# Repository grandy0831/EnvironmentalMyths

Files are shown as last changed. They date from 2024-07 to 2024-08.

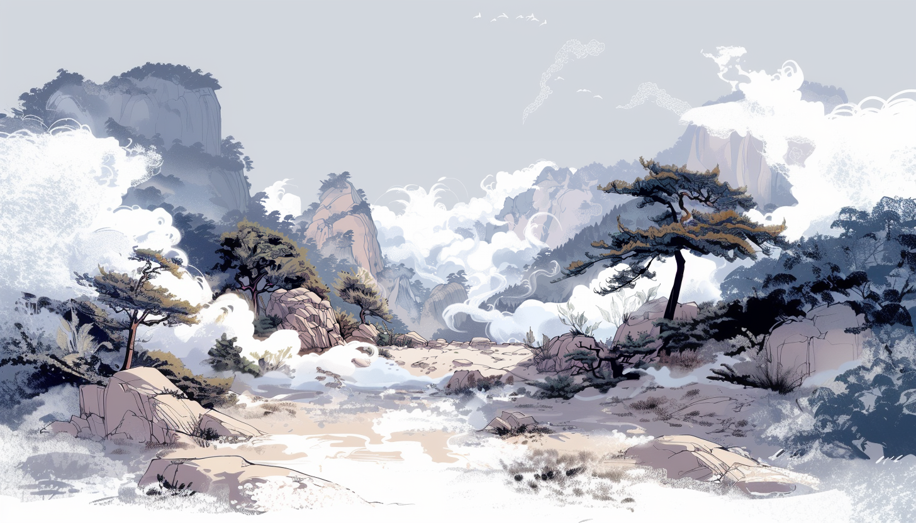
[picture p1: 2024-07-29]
Mythology Pictures/Wind-S2/W2-Background-generated by AI/W2-2.png

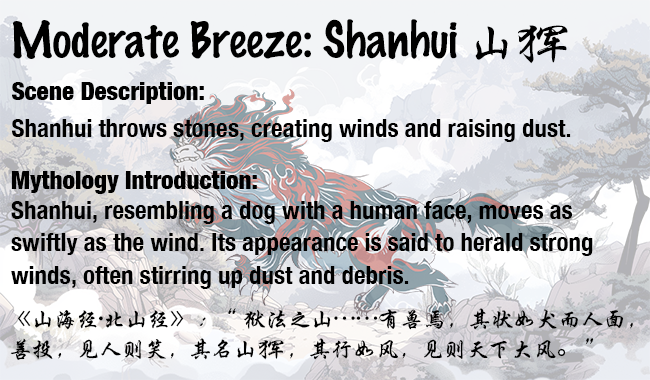
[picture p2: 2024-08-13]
Code/Final/Myths/With screen/png/Shanhui.png

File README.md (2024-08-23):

# Environmental Myths: The Fusion of Ancient Mythology and Modern Technology



## Project Overview
The Environmental Myths project brings together ancient Chinese myths and modern technology to demonstrate how ancient people interpreted natural phenomena. Utilising sensors to monitor temperature, humidity, and wind, it transforms this environmental data into dynamic displays through artistic installations featuring mechanical structures. This innovative approach not only educates the public about traditional culture and environmental changes but also revitalises ancient stories, fostering an appreciation for cultural heritage and environmental science.

## Research Questions
**Main Question:**
- How can traditional Chinese myths be integrated with modern environmental sensor technology to visualise changes in the environment?

**Sub-Questions:**
- How can a reliable outdoor environmental monitoring device be designed and constructed for long-term operation?
- How can artistic installations be designed to display environmental data captured by sensors?

## Technical Details

### Personal Weather Station Design
- **Sensor Selection**
  - DHT22 for humidity and temperature measurement.
  - Pulse Output Wind Speed Sensor for wind speed detection.
  
- **Hardware Assembly**
  - Powered by a 3.7V 1000mAh rechargeable lithium polymer battery.
  - Supported by a 1W 80*100 solar panel.
  - Managed by the DFRobot Solar Power Manager 5V.
  - Controlled by Arduino NANO ESP32 Nano for efficient data processing.

- **Enclosure**
  - Stevenson screen model 3D-printed in PETG material, which is noted for its high strength and impact resistance, ensuring durability in outdoor environments.

- **Code Implementation**
  - Incorporates Wi-Fi connectivity and an MQTT client for seamless data transmission.
  - Utilises ESP32 deep sleep mode to significantly reduce power consumption during idle times, ensuring long-term deployment without frequent maintenance.

### Artistic Installation Device Design

- **Hardware Assembly**
  - **Controller**: Utilises Arduino GIGA R1 WI-FI for robust control, featuring an extensive number of GPIOs and dedicated connectors.
  - **Servo Motors**: Three continuous rotation servos to control the movements of characters on the stage. One 25kg torque servo for angular control, tasked with switching between different scenes.
  - **Display**: Integrates a GIGA Display Shield to introduce and explain each scene.
  - **Presence Detection**: Employs a PIR sensor to detect the presence of viewers, activating the scene's movements when someone is nearby.

- **Code Implementation**
  - **Graphics and Video**: Uses ArduinoGraphics and Arduino_H7_Video.h libraries to display images.
  - **Connectivity**: Connects to a MQTT server via WI-FI to receive data from the weather station.
  - **Actuation**: Controls the servos based on received environmental data to switch scenes dynamically as environmental conditions change.

- **Enclosure Design**
  - **Stage Design**: Entirely original design created in FUSION360 for a rotatable stage that transitions between three scenes.
  - **Manufacturing**: Constructed using 3D printing, assembling the multi-scene stage prototype for interactive display.

## Installation Guide

### Hardware Installation Steps

#### Environmental Monitoring Station Setup:
- **Hardware Connection Diagram**:

PWS

- **Code Repository**: [Access the code here](https://github.com/grandy0831/EnvironmentalMyths/tree/main/Code/Final/PWS)
- **Enclosure Printing Model**: [Download the 3D model here](https://www.thingiverse.com/thing:3615016#google_vignette)
- **Internal Setup Images**:

5101723710179_ pic

#### Artistic Installation Setup:
- **Hardware Connection Diagram**:

stage_bb

- **Layer Model Functionality**:
  - **Top Layer (L0)**: Combines three devices.
  - **Scene Display (L1-1)**: Details the exhibition of scenes.
  - **Continuous Rotation Servo Space (L1-2)**: Houses the internal mechanics.
  
  5331723711250_ pic

  - **Rotation Platform (L2-1)**: Supports scene rotation, allowing space for wiring.
    
  5321723711248_ pic
  
  - **Central Servo Fixation (L2-1.5)**: Holds the central servo controlling stage rotation.
    
  5341723711592_ pic
  
  - **Display and Controls (L2-2-1, L2-2-2, L2-2-3)**: Accommodates the display, PIR sensor, switches, power sockets, and space for physical components and wiring.
  
  5311723711247_ pic

- **Model Links**: [Access models here](https://github.com/grandy0831/EnvironmentalMyths/tree/main/Model/STAGE)
- **Assembly Images by Layers**:
  
5281723711241_ pic
5291723711243_ pic

- **Final Device Scenes Presentation**:










## Deployment and Exhibition

### Weather Station Deployment
- **Deployment Photos**:
  
5231723710192_ pic
5241723710193_ pic
5261723710196_ pic

- **Operational Showcase**:
  
5031723217820_ pic

### Art Installation Setup
- **Scene Stage Deployment**: Photographs of the scene stage setup at the exhibition site.
  
c6b02fe9f156e05483c8268d89080cd7

- **Artistic Device Introduction**: [Learn more about the artistic installation](https://environmentalmyths.com/myths)

## Conclusion
This project has successfully integrated physical devices with artistic displays, creating an innovative installation that can monitor environmental data in real-time while dynamically presenting mythological stories.

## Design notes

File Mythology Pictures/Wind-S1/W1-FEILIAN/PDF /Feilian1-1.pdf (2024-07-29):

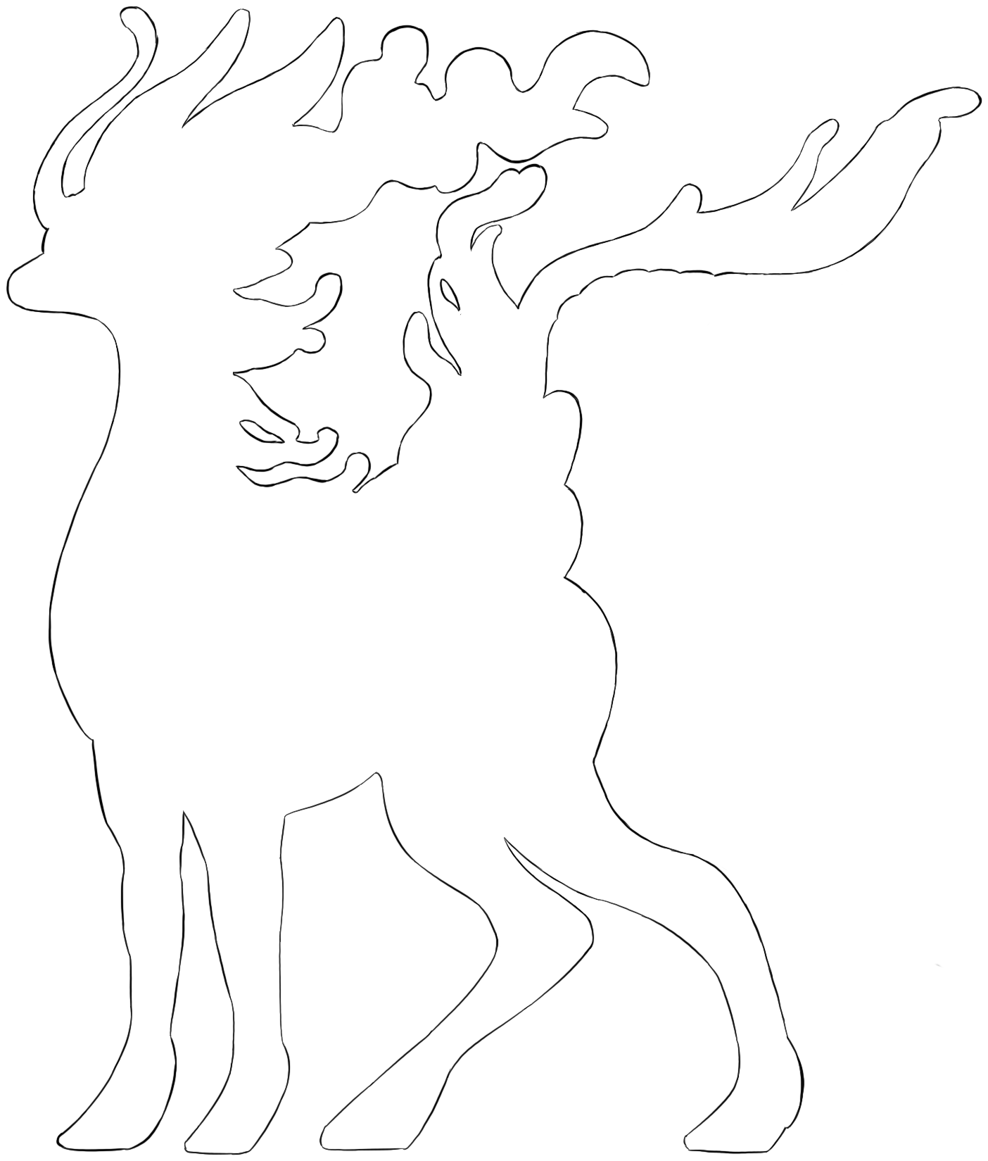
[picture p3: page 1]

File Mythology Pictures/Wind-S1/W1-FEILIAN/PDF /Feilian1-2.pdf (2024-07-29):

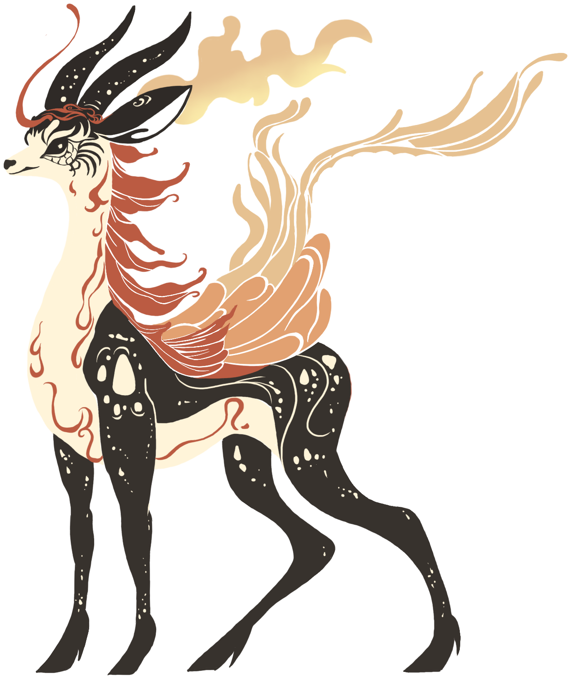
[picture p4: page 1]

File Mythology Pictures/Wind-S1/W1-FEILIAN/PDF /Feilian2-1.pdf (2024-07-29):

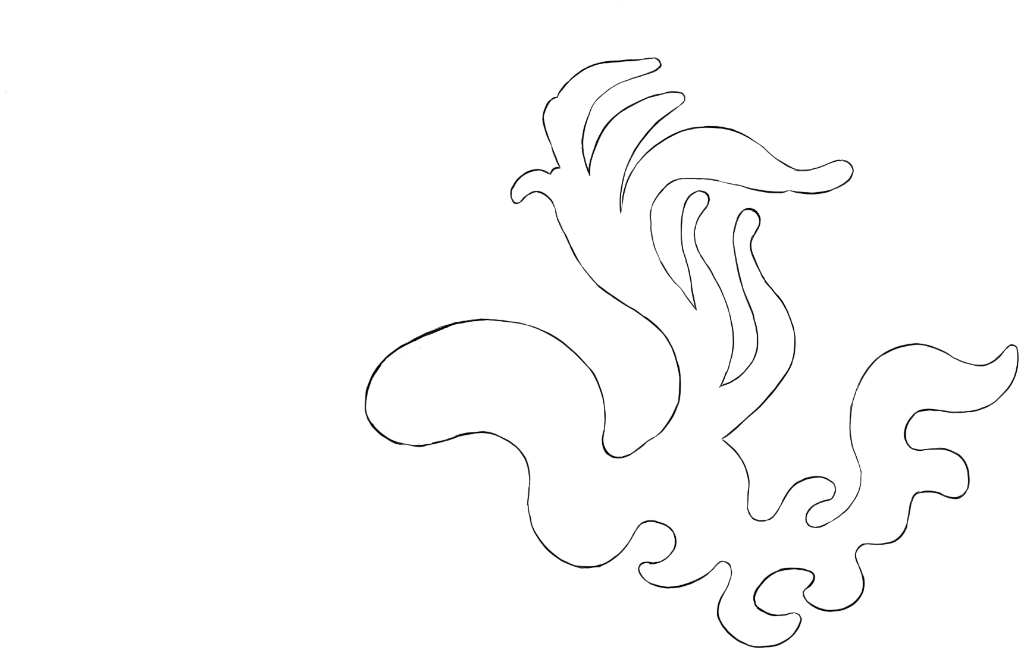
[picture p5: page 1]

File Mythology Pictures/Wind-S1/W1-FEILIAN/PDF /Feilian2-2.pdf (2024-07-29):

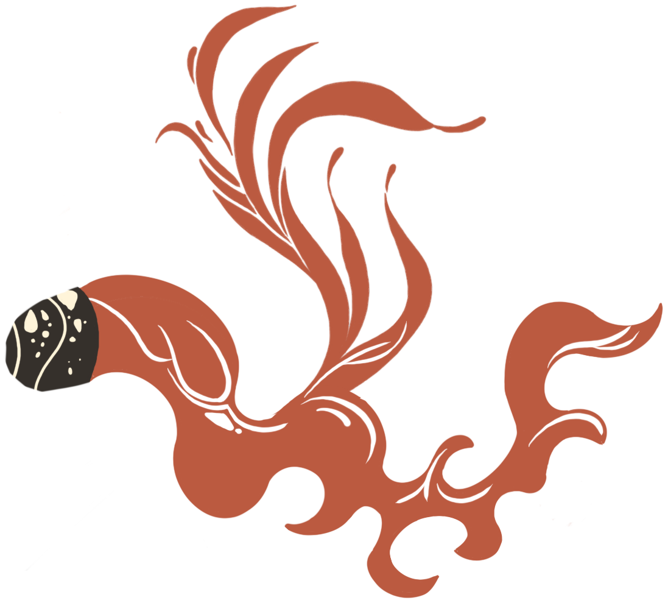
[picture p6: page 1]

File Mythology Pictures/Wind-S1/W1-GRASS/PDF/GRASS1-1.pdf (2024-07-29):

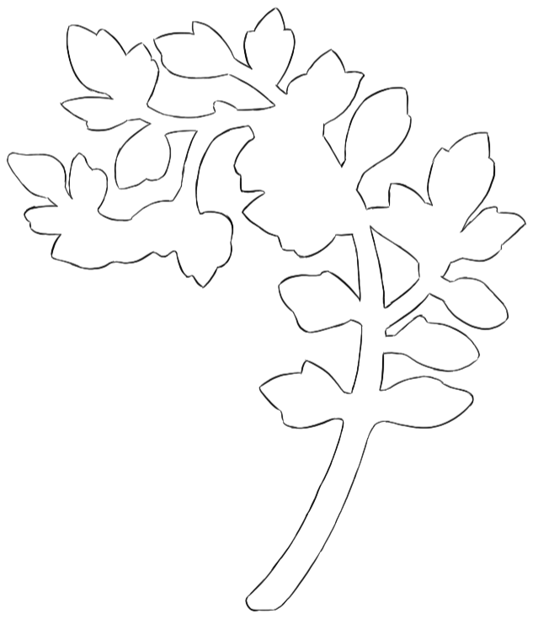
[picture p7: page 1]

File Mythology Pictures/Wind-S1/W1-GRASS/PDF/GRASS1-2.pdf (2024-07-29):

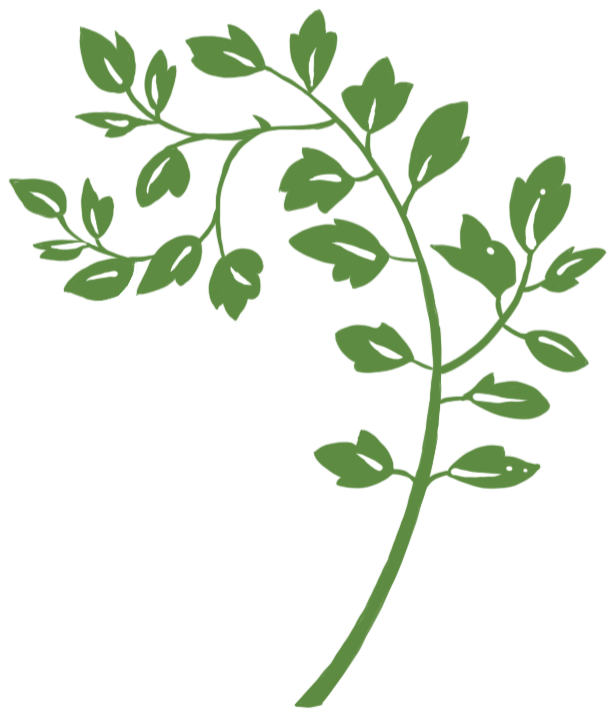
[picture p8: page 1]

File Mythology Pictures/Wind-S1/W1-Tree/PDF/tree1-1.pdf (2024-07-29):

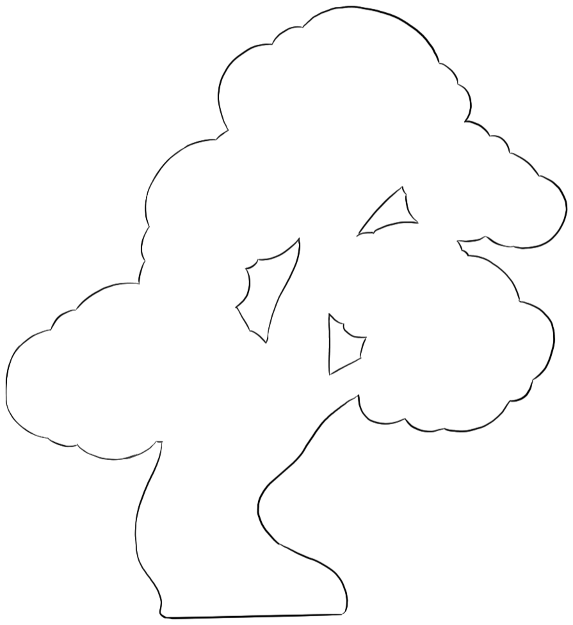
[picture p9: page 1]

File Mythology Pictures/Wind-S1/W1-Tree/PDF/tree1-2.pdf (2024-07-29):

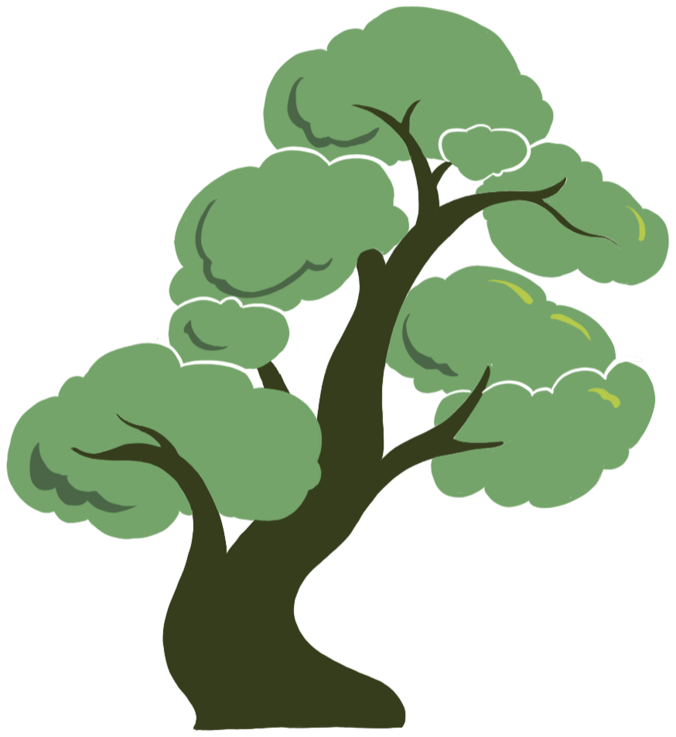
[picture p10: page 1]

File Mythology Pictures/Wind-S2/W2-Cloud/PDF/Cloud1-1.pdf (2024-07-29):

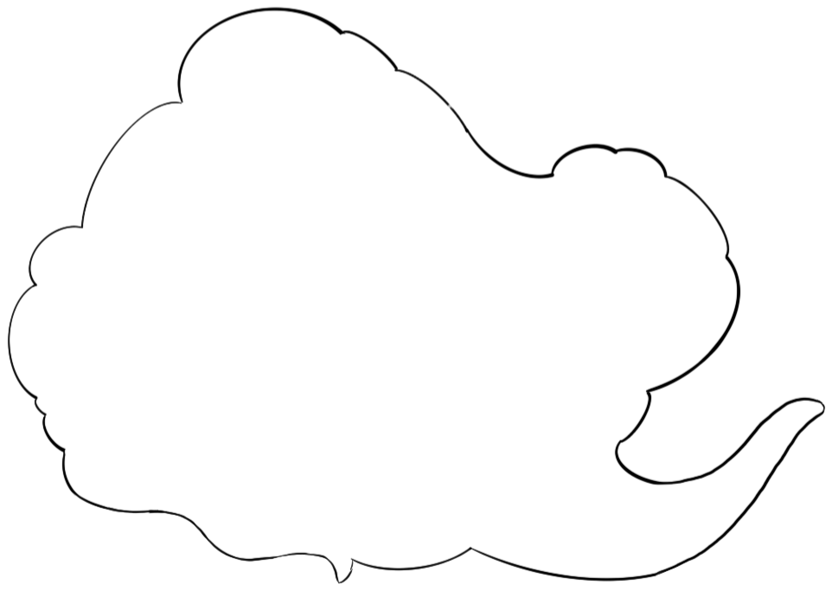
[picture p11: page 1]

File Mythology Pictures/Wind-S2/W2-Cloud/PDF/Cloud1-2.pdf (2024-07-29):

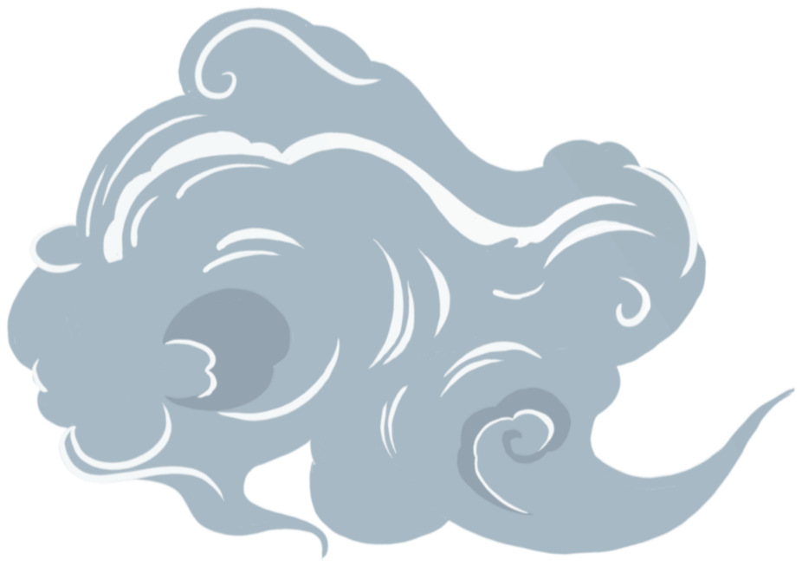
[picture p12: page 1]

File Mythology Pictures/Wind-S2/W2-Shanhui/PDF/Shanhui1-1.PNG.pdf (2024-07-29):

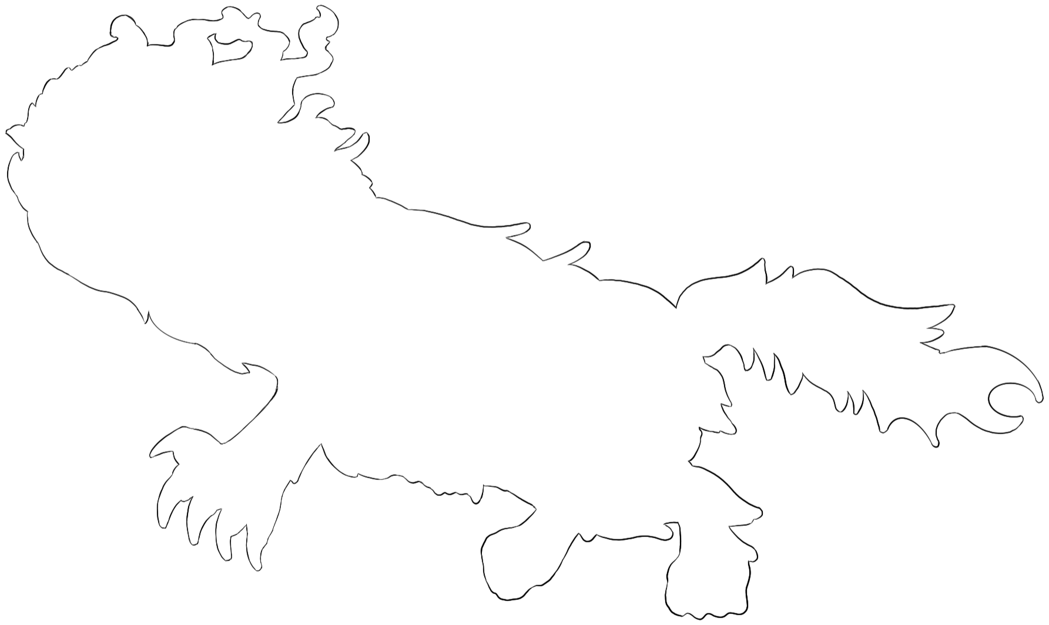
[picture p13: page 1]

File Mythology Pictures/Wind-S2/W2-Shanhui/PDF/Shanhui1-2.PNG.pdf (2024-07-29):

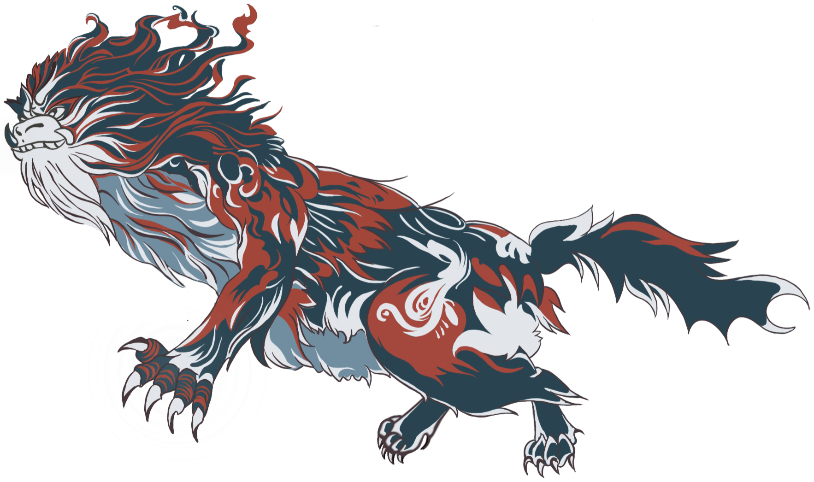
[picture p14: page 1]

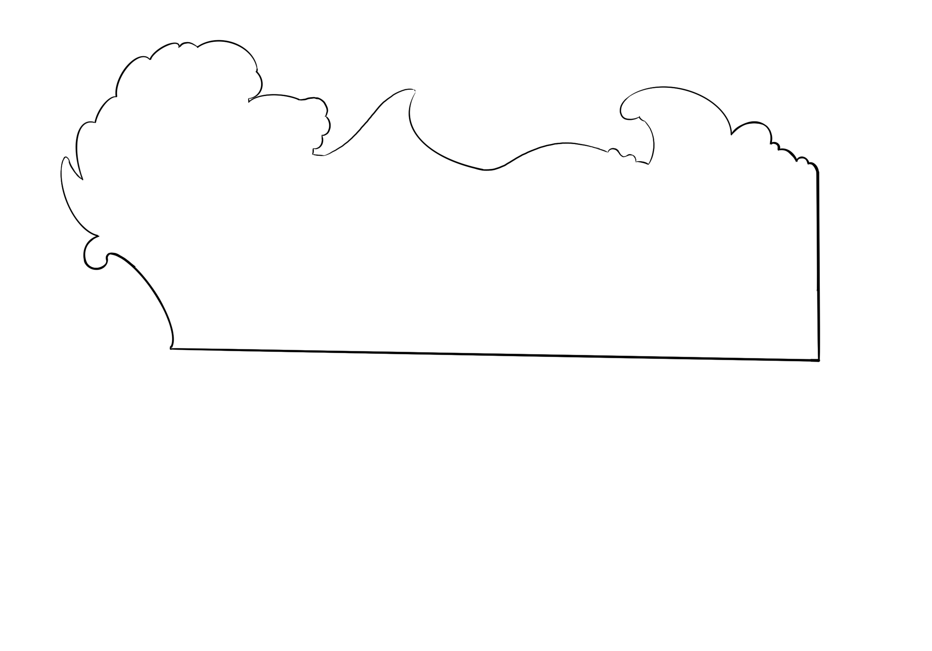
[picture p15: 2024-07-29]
Mythology Pictures/Wind-S3/W3-Wave/PNG/wave1-1.PNG

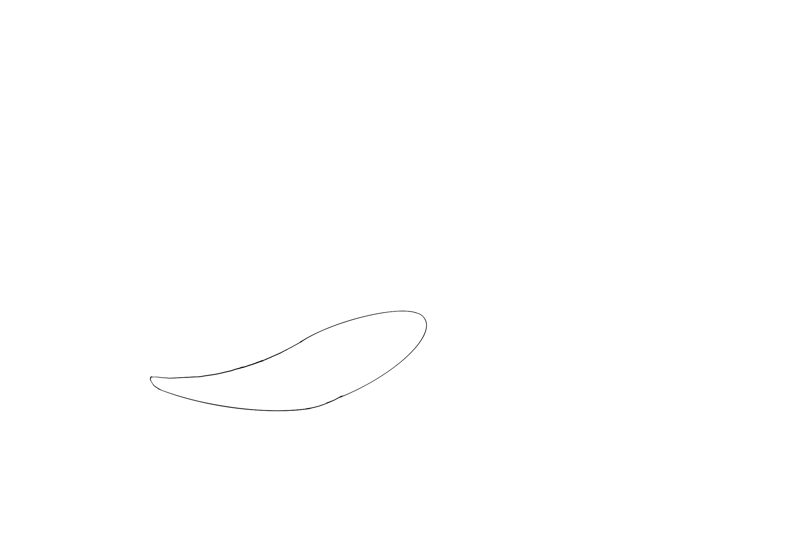
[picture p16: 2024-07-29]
Mythology Pictures/Wind-S3/W3-Kunpeng/PNG/Kunpeng1-1.PNG

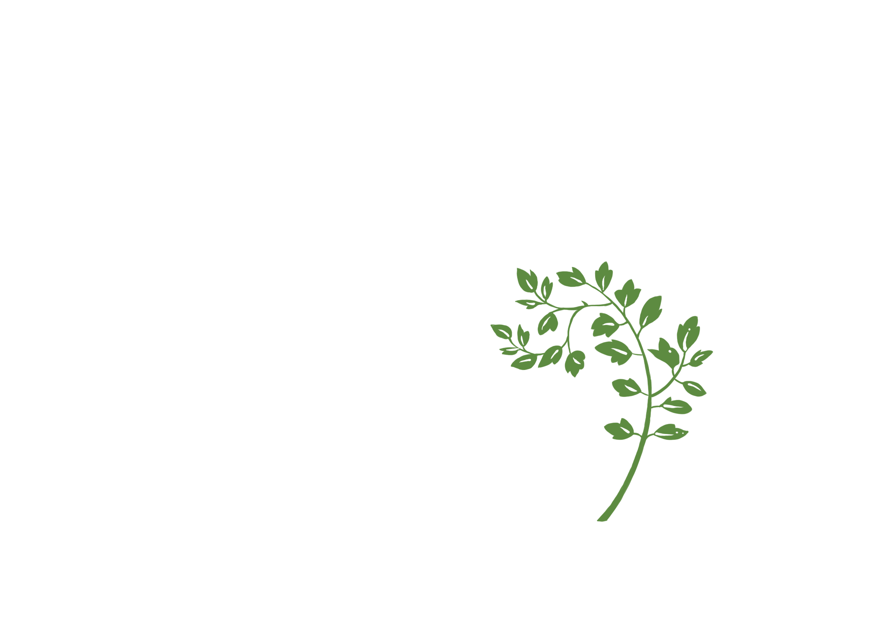
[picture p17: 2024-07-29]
Mythology Pictures/Wind-S1/W1-GRASS/PNG/GRASS1-2.PNG

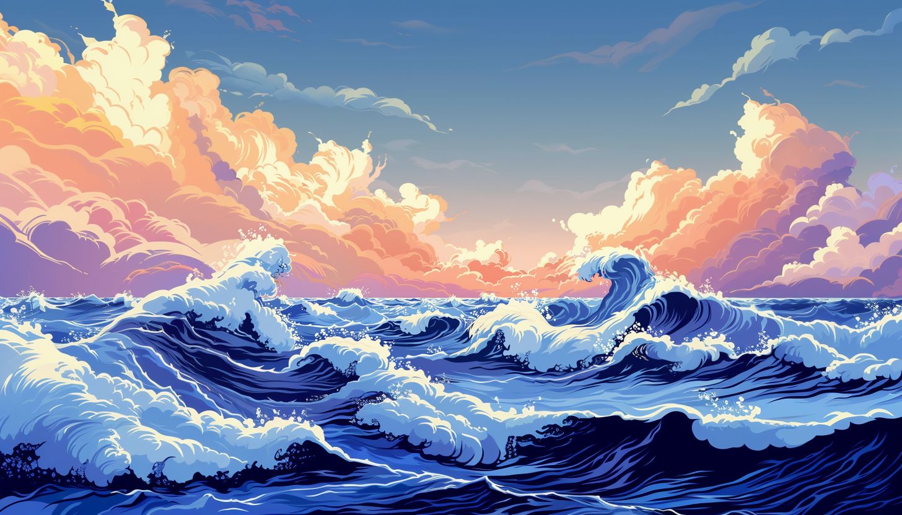
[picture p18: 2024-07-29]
Mythology Pictures/Wind-S3/W3-Background-generated by AI/W3-2.png

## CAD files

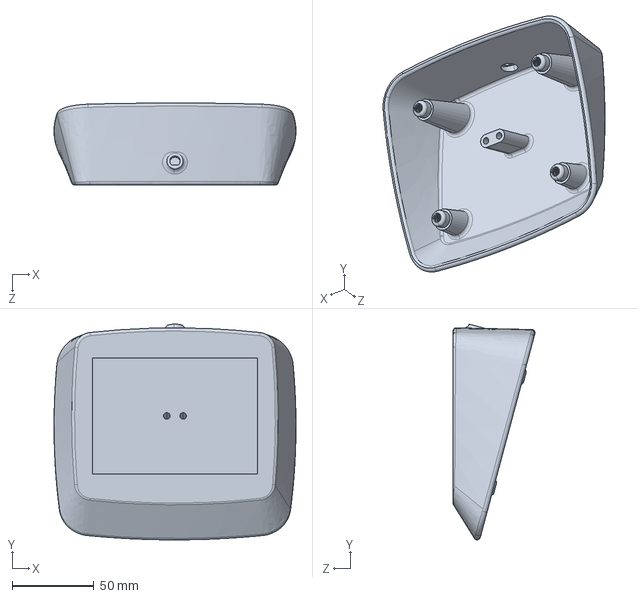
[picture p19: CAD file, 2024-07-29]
Model/PWS/Stevenson Screen for Solar Weather Station V2/Screen_Top_Cover.STEP
147.8 x 131.8 x 50.1 mm

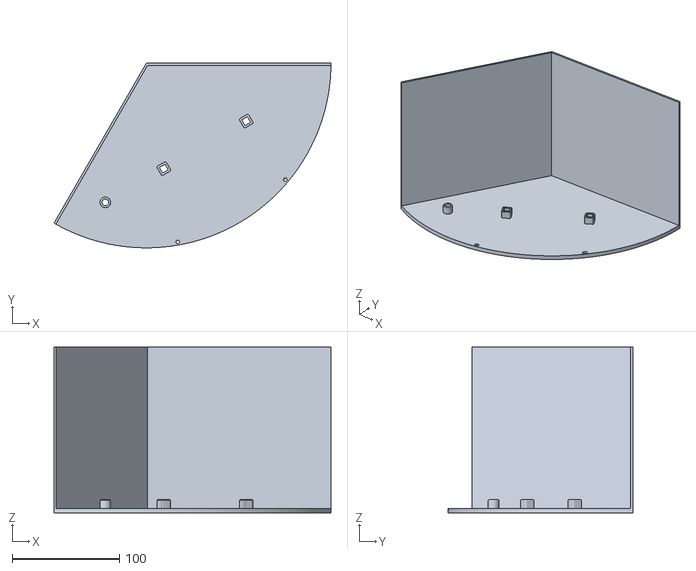
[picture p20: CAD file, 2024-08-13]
Model/STAGE/L1-1-HUM/L1-H3 .stl
257.7 x 171.8 x 154.4

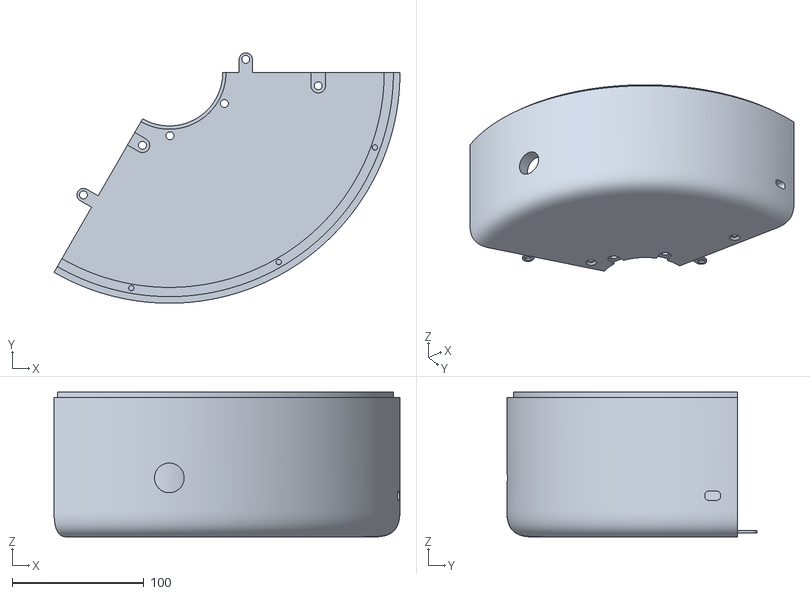
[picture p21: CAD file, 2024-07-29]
Model/STAGE/L2-2-3.stl
262.5 x 190.0 x 110.0

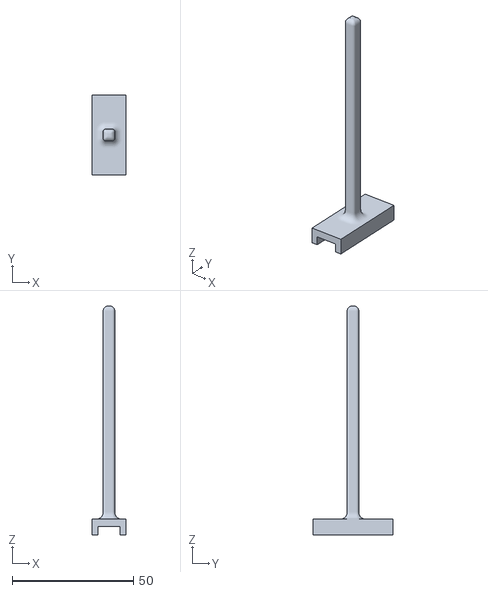
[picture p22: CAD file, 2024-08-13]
Model/STAGE/Other/G2.stl
14.0 x 33.0 x 94.5

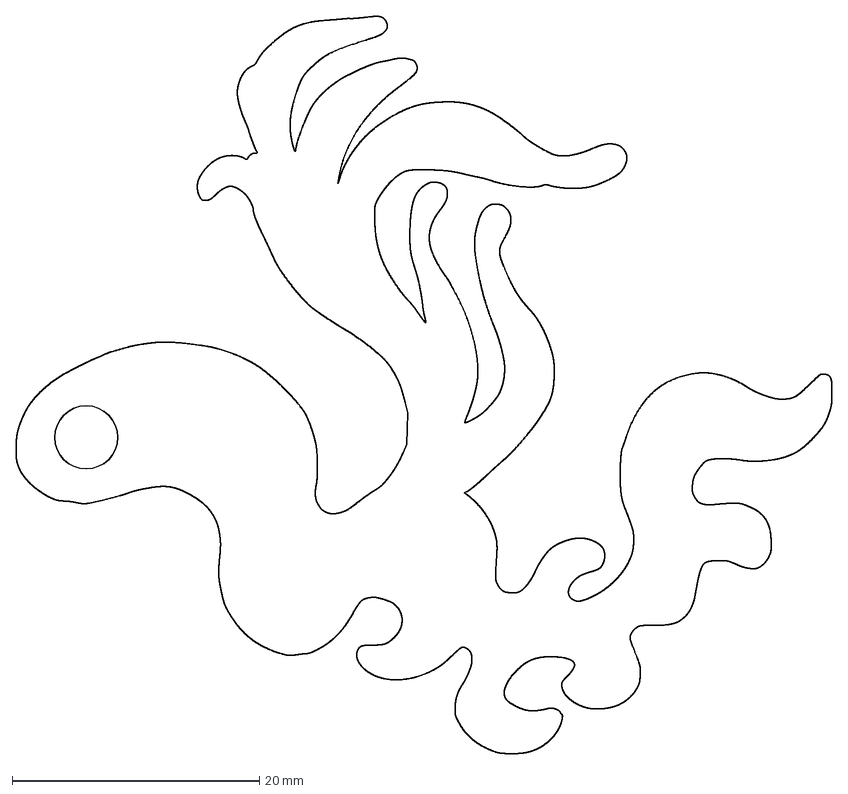
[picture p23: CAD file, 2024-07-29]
Mythology Pictures/Wind-S1/W1-FEILIAN/DXF /Feilian2.dxf
66.0 x 59.6 mm

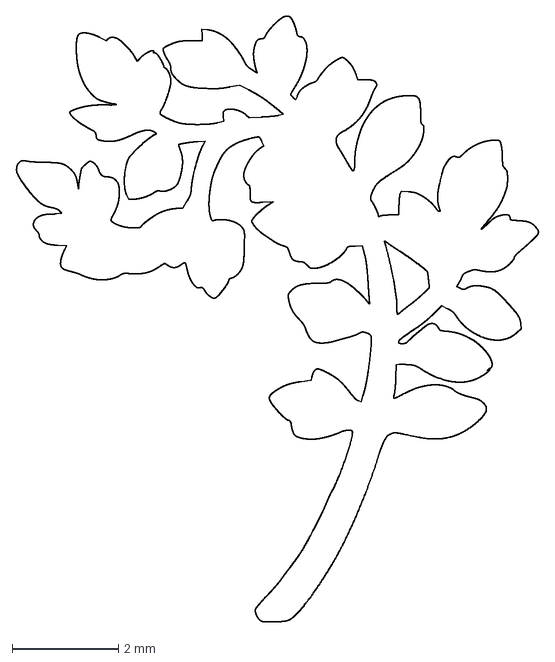
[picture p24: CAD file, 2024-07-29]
Mythology Pictures/Wind-S1/W1-GRASS/DXF/GRASS.dxf
9.81 x 11.4 mm

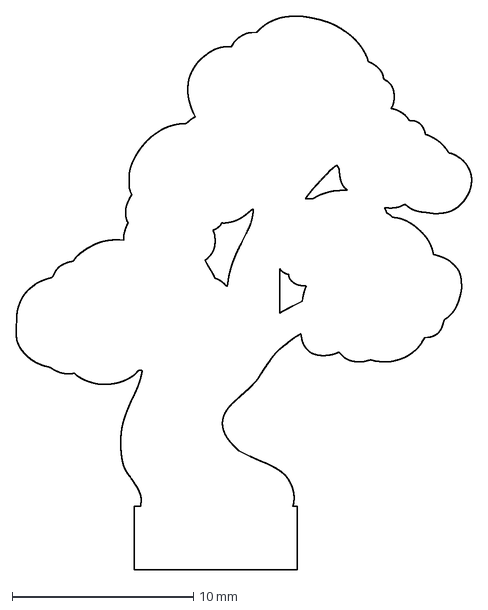
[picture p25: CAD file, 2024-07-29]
Mythology Pictures/Wind-S1/W1-Tree/DXF/tree.dxf
25.1 x 30.5 mm

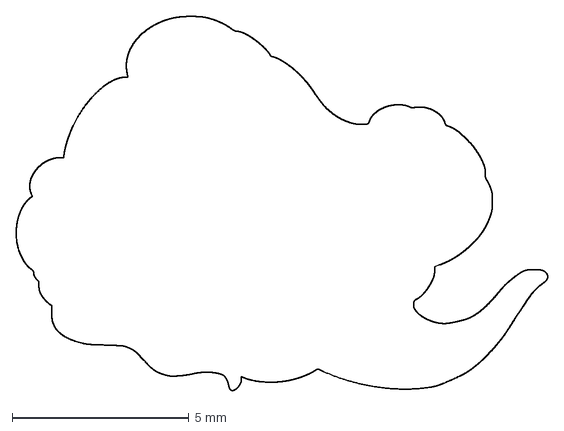
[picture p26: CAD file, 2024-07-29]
Mythology Pictures/Wind-S2/W2-Cloud/DXF/Cloud.dxf
15.0 x 10.6 mm

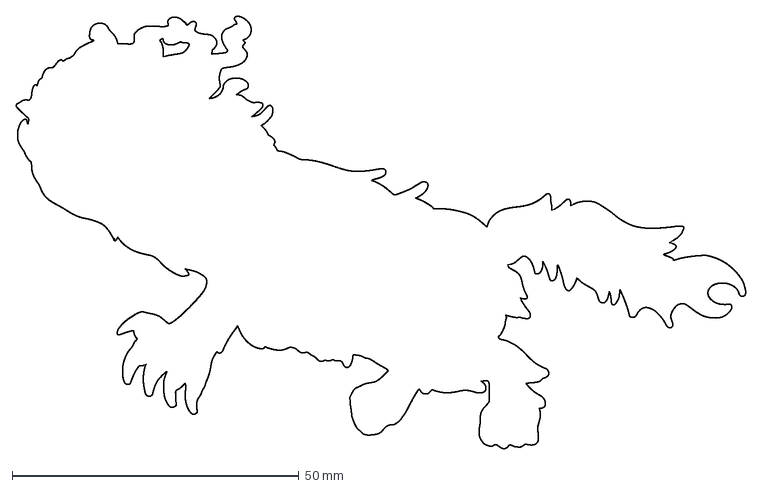
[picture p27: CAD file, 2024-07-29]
Mythology Pictures/Wind-S2/W2-Shanhui/DXF/Shanhui1.dxf
127.2 x 75.4 mm

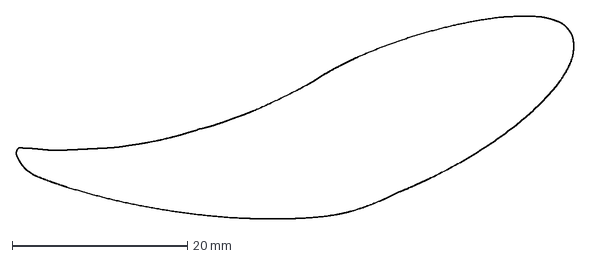
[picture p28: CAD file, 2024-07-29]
Mythology Pictures/Wind-S3/W3-Kunpeng/DXF/Kunpeng2.dxf
63.6 x 23.1 mm

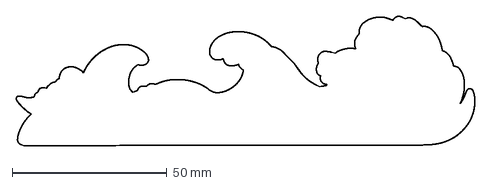
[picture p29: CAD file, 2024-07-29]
Mythology Pictures/Wind-S3/W3-Wave/DXF/wave1.dxf
148.2 x 41.8 mm

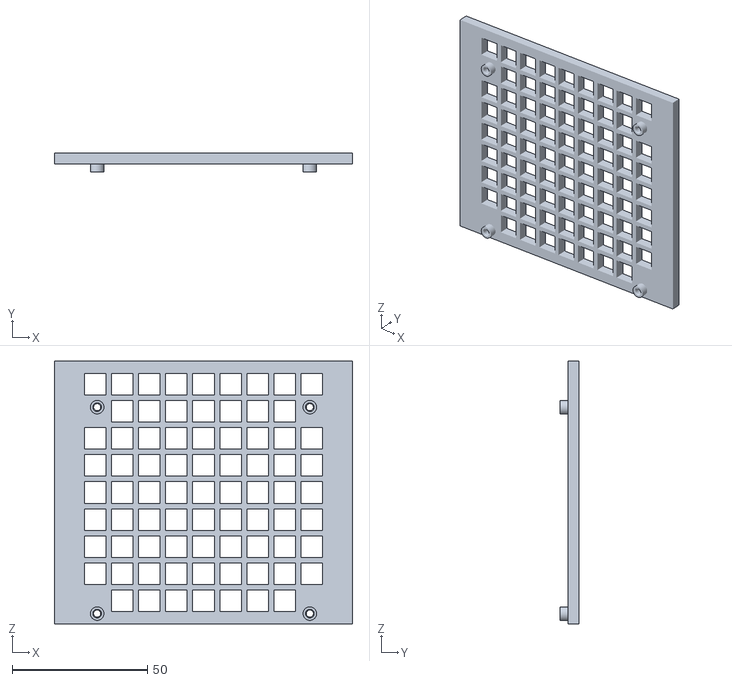
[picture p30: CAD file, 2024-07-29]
Model/PWS/Stevenson Screen for Solar Weather Station V2/Stevenson_Screen_PCB_Mount_Frame.STL
110.0 x 7.00 x 97.0

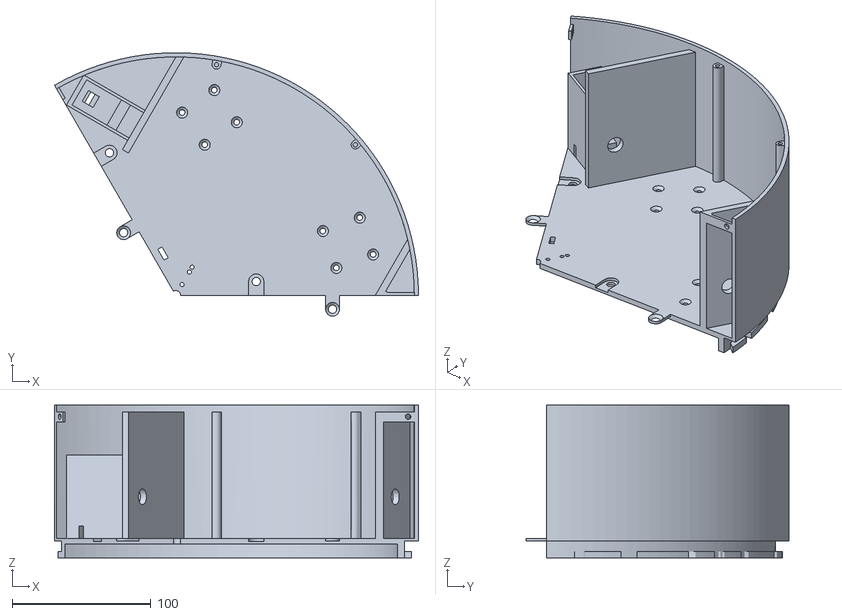
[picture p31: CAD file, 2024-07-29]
Model/STAGE/L1-2x3.stl
262.5 x 190.0 x 110.0

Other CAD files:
Model/STAGE/L1-1-TEMP/L1-T2.stl
Model/STAGE/L1-1-WIND/L1-W3.stl
Model/STAGE/L1-1-HUM/L1-H2.stl
Model/STAGE/L1-1-TEMP/L1-T1 .stl
Model/STAGE/L1-1-WIND/L1-W1.stl
Model/PWS/Stevenson Screen for Solar Weather Station V2/base2.stl
Model/PWS/Stevenson Screen for Solar Weather Station V2/windbase.stl
Model/STAGE/L0.stl
Model/STAGE/L1-1-HUM/L1-H1.stl
Model/STAGE/L1-1-TEMP/L1-T3 .stl
Model/STAGE/L1-1-WIND/L1-W2.stl
Model/STAGE/L2-1.5.stl
Model/STAGE/L2-1x3.stl
Model/STAGE/L2-2-1.stl
Model/STAGE/L2-2-2.stl
Model/STAGE/Other/G.stl
Model/STAGE/Other/G1.stl
Model/STAGE/Other/G3.stl
Mythology Pictures/Wind-S1/W1-FEILIAN/DXF /Feilian1.dxf
Mythology Pictures/Wind-S2/W2-Shanhui/DXF/Shanhui2.dxf
Mythology Pictures/Wind-S3/W3-Kunpeng/DXF/Kunpeng1.dxf
Mythology Pictures/Wind-S3/W3-Wave/DXF/wave2.dxf

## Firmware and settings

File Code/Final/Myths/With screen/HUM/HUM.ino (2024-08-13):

#include <WiFi.h>
#include <PubSubClient.h>
#include <Servo.h>

// Includes secret passwords and configurations
#include "password_management.h"

#include "Arduino_H7_Video.h"
#include "ArduinoGraphics.h"

#include "img_arduinologo.h"

#define INCBIN_PREFIX
#include "incbin.h"

// Defines network and MQTT broker details, sourced from configuration files
const char* ssid = SECRET_SSID;
const char* password = SECRET_PASS;
const char* mqtt_server = SECRET_MQTTSERVER;
const int mqtt_port = SECRET_MQTTPORT;
const char* mqtt_user = SECRET_MQTTUSER;
const char* mqtt_password = SECRET_MQTTPASS;

WiFiClient espClient;
PubSubClient client(espClient);
Servo angleServo;  // Servo for angle control
Servo servoOne;
Servo servoTwo;
Servo servoThree;
int pirPin = 2;                 // Pin for PIR sensor
int switchPin = 3;              // Pin for switch
bool pirState = false;          // Current state of the PIR sensor
unsigned long lastMsgTime = 0;  // Tracks the time of the last message request
long interval = 60000;          // Interval for message requests (60 seconds)
int lasthumidity = 0;        // Stores the last humidity value
int delayTime = 60;             // Delay time to control servo movement speed

/*
INCBIN(test, "C:/Users/name/Downloads/test.bin");
INCBIN(test2, "C:/Users/name/Downloads/test2.bin");
INCBIN(test3, "C:/Users/name/Downloads/test3.bin");
For Windows
*/

INCBIN(test, "/Users/grandy_chan/Downloads/test.bin");
INCBIN(test2, "/Users/grandy_chan/Downloads/test2.bin");
INCBIN(test3, "/Users/grandy_chan/Downloads/test3.bin");
//For Mac


Arduino_H7_Video Display(800, 480, GigaDisplayShield);
//Arduino_H7_Video Display(1024, 768, USBCVideo);

Image img_test(ENCODING_RGB16, (uint8_t*)testData, 650, 380);
// Image img_test2(ENCODING_RGB16, (uint8_t *) test2Data, 800, 480);
Image img_test2(ENCODING_RGB16, (uint8_t*)test2Data, 650, 380);
Image img_test3(ENCODING_RGB16, (uint8_t*)test3Data, 650, 380);

unsigned long pirLastTriggered = 0;  // Time when the PIR sensor was last triggered
const long pirHoldTime = 10000;      // Duration for which the PIR sensor activation is considered

void setup() {
  Display.begin();
  setup_wifi();
  pinMode(pirPin, INPUT);            // Sets the PIR sensor pin as input
  pinMode(switchPin, INPUT_PULLUP);  // Sets the switch pin as input with pull-up
  client.setServer(mqtt_server, mqtt_port);
  client.setCallback(callback);  // Sets the MQTT message reception callback function
  angleServo.attach(9);
  servoOne.attach(10);
  servoTwo.attach(11);
  servoThree.attach(12);
  reconnect();  // Connects to the MQTT server
}

void loop() {
  if (digitalRead(switchPin) == LOW) {  // If the switch is pressed
    if (!client.connected()) {
      reconnect();  // Ensures a continuous connection to the MQTT server
    }

    bool currentPirState = digitalRead(pirPin);
    if (currentPirState) {
      pirLastTriggered = millis();  // Updates the time the PIR sensor was triggered
    }

    if (millis() - pirLastTriggered < pirHoldTime) {
      // Controls other servos based on humidity
      Display.beginDraw();
      Display.image(lasthumidity < 30 ? img_test : (lasthumidity >= 30 && lasthumidity <= 60 ? img_test2 : img_test3), 75, 50);
      Display.endDraw();
      servoOne.writeMicroseconds(lasthumidity < 30 ? 1800 : 1500);
      servoTwo.writeMicroseconds(lasthumidity >= 30 && lasthumidity <= 60 ? 1600 : 1500);
      servoThree.writeMicroseconds(lasthumidity > 60 ? 1700 : 1500);
    } else {
      // If the PIR sensor is not retriggered within the specified time, reset servos to neutral position
      servoOne.writeMicroseconds(1500);
      servoTwo.writeMicroseconds(1500);
      servoThree.writeMicroseconds(1500);
    }
  } else {
    // Set all servos to neutral position if the switch is not pressed
    servoOne.writeMicroseconds(1500);
    servoTwo.writeMicroseconds(1500);
    servoThree.writeMicroseconds(1500);
  }
}


void setup_wifi() {
  Serial.begin(115200);
  Serial.println("Connecting to WiFi...");
  WiFi.begin(ssid, password);

  while (WiFi.status() != WL_CONNECTED) {
    delay(500);
    Serial.print(".");  // Prints a dot during the connection attempt
  }

  Serial.println("");
  Serial.println("WiFi connected");
  Serial.println("IP address: ");
  Serial.println(WiFi.localIP());
}

void callback(char* topic, byte* payload, unsigned int length) {
  char message[length + 1];  // Creates a string to store the message content
  for (int i = 0; i < length; i++) {
    message[i] = (char)payload[i];  // Converts payload to string
  }
  message[length] = '\0';  // Ensures the string is null-terminated

  Serial.print("Message arrived [");
  Serial.print(topic);
  Serial.print("]: ");
  Serial.println(message);

  // If the message is related to humidity
  if (strcmp(topic, "student/EM1/zczqgch/humidity") == 0) {
    lasthumidity = atoi(message);  // Converts the message to an integer
    int targetAngle = lasthumidity < 30 ? 0 : (lasthumidity >= 30 && lasthumidity <= 60 ? 80 : 160);
    smoothMoveServo(angleServo, targetAngle);  // Smoothly moves the servo to the target angle
  }
}

// A function to smoothly move a servo to a specified angle
void smoothMoveServo(Servo servo, int targetAngle) {
  int currentAngle = servo.read();                   // Reads the current angle
  int step = (currentAngle < targetAngle) ? 1 : -1;  // Determines the direction of rotation
  while (currentAngle != targetAngle) {
    currentAngle += step;
    servo.write(currentAngle);  // Gradually changes the angle
    delay(delayTime);           // Delay to control the speed of the movement
  }
}

void reconnect() {
  // Attempts to reconnect if not connected to the MQTT server
  while (!client.connected()) {
    Serial.print("Attempting MQTT connection...");
    String clientId = "arduinoClient-";
    clientId += String(random(0xffff), HEX);
    if (client.connect(clientId.c_str(), mqtt_user, mqtt_password)) {
      Serial.println("connected");
      client.subscribe("student/EM1/zczqgch/humidity", 1);  // Subscribes to the humidity topic
      client.loop();
    } else {
      Serial.print("failed, rc=");
      Serial.print(client.state());
      Serial.println(" try again in 5 seconds");
      delay(5000);
    }
  }
}

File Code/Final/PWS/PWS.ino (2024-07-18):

// Include necessary libraries for WiFi, time, sensor data handling, and MQTT communication
#include <WiFi.h>
#include <NTPClient.h>
#include <WiFiUdp.h>
#include <Timezone.h>
#include <DHT.h>
#include <PubSubClient.h>

// Include secret passwords and configurations
#include "password_management.h"

// Define network and MQTT broker details, pulled from password_management.h
const char* ssid     = SECRET_SSID;
const char* password = SECRET_PASS;
const char* mqtt_server = SECRET_MQTTSERVER;
const int mqtt_port = SECRET_MQTTPORT;
const char* mqtt_user = SECRET_MQTTUSER;
const char* mqtt_password = SECRET_MQTTPASS;

// DHT sensor setup
#define DHTPIN 5 // Digital pin connected to the DHT sensor
#define DHTTYPE DHT22 // DHT22 type sensor
DHT dht(DHTPIN, DHTTYPE);

// Wind speed measurement setup
#define WIND_SPEED_PIN 2 // Digital pin for wind speed sensor
volatile int windCount = 0; // Counts the wind sensor signal interruptions
unsigned long lastDebounceTime = 0; // Timestamp of last signal debounce
unsigned long debounceDelay = 1000; // Debounce delay in milliseconds

// Time zone configuration for UK
TimeChangeRule BST = {"BST", Last, Sun, Mar, 1, 60}; // British Summer Time
TimeChangeRule GMT = {"GMT", Last, Sun, Oct, 2, 0}; // Greenwich Mean Time
Timezone UK(BST, GMT);

// NTP Client for time synchronization
WiFiUDP ntpUDP;
NTPClient timeClient(ntpUDP, "pool.ntp.org", 0, 60000);

// MQTT client setup
WiFiClient espClient;
PubSubClient client(espClient);

// Time tracking for sensor data publication
unsigned long lastTime = 0;
unsigned long interval = 30000; // Set the interval time to 30 seconds

// Interrupt service routine for detecting wind speed
void IRAM_ATTR detectWind() {
  windCount++; // Increment wind count on each interrupt
}

// Initial setup function
void setup() {
  Serial.begin(115200); // Start serial communication at 115200 baud rate
  dht.begin(); // Initialize DHT sensor
  setup_wifi(); // Connect to WiFi
  client.setServer(mqtt_server, mqtt_port); // Configure MQTT server
  timeClient.begin(); // Start NTP client
  
  pinMode(WIND_SPEED_PIN, INPUT_PULLUP); // Setup wind speed pin
  attachInterrupt(digitalPinToInterrupt(WIND_SPEED_PIN), detectWind, FALLING); // Attach interrupt

  // Enable deep sleep with a wakeup time of 60 seconds
  esp_sleep_enable_timer_wakeup(180 * 1000000);
}

// Calculate wind speed based on sensor interrupts
float calculateWindSpeed() {
    float pulsesPerSecond = windCount / (interval / 1000.0);
    float windSpeed = pulsesPerSecond * 0.0875;
    windCount = 0;
    return windSpeed;
}

// Main loop function
void loop() {
  if (!client.connected()) {
    reconnect(); // Reconnect to MQTT if disconnected
  }
  client.loop(); // Maintain MQTT connection

  if (millis() - lastTime > interval) {
    lastTime = millis(); // Update last time
    timeClient.update(); // Update NTP client time
    printFormattedTime(); // Print formatted time

    float t = dht.readTemperature(); // Read temperature from DHT sensor
    float h = dht.readHumidity(); // Read humidity from DHT sensor
    float windSpeed = calculateWindSpeed(); // Calculate wind speed

    // Prepare payload for MQTT
    char temp[50], hum[50], windStr[50];
    snprintf(temp, sizeof(temp), "%.2f", t);
    snprintf(hum, sizeof(hum), "%.2f", h);
    snprintf(windStr, sizeof(windStr), "%.2f", windSpeed);

    // Check sensor readings for validity before publishing
    if (!isnan(h) && !isnan(t)) {
      Serial.printf("Temperature: %s°C, Humidity: %s%%, Wind Speed: %s m/s\n", temp, hum, windStr);
      client.publish("student/EM1/zczqgch/temperature", temp, true);
      client.publish("student/EM1/zczqgch/humidity", hum, true);
      client.publish("student/EM1/zczqgch/windspeed", windStr, true);
    } else {
      Serial.println("Failed to read from DHT sensor!");
    }

    // Enter deep sleep mode after publishing
    delay(2000); // Delay to ensure message is sent before sleeping
    Serial.println("Entering deep sleep mode now");
    esp_deep_sleep_start();
  }
}

// Setup WiFi connection
void setup_wifi() {
  WiFi.begin(ssid, password);
  Serial.print("Connecting to ");
  Serial.println(ssid);
  while (WiFi.status() != WL_CONNECTED) {
    delay(500);
    Serial.print(".");
  }
  Serial.println("\nWiFi connected.");
  Serial.print("IP address: ");
  Serial.println(WiFi.localIP());
}

// Attempt to reconnect to MQTT server
void reconnect() {
  while (!client.connected()) {
    Serial.print("Attempting MQTT connection...");
    char clientId[25];
    snprintf(clientId, sizeof(clientId), "arduinoClient-%lu", random(0, 10000));
    if (client.connect(clientId, mqtt_user, mqtt_password)) {
      Serial.println("connected");
    } else {
      Serial.print("failed, rc=");
      Serial.print(client.state());
      Serial.println(" try again in 5 seconds");
      delay(5000);
    }
  }
}

// Print the formatted current time
void printFormattedTime() {
  time_t utc = timeClient.getEpochTime();
  time_t local = UK.toLocal(utc);  

  struct tm * ptm = localtime(&local);
  char timeString[40];
  strftime(timeString, sizeof(timeString), "%Y-%m-%d %H:%M:%S", ptm);
  Serial.print(timeString);
  Serial.print(" - ");
}

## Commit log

2024-06-02 Test to control four servos at the same time
2024-07-29 Add model
    [L0.stl, L1-2x3.stl, L1-W1.stl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]
2024-07-29 Add pics
    [Cloud.dxf, Feilian1.dxf, Feilian2.dxf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]
2024-08-13 Add code
    [G.stl, G1.stl, G2.stl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]
